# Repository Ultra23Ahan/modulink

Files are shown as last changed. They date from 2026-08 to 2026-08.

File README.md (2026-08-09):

## This specific repository is for the motor part of modulink.

What modulink is:

# ModuLink

ModuLink is a 90% 3d printed and modular system. It is a system of motors, gears, gearboxes, and many other components that can be used to create anything your heart desires.

# Usage Instructions

Make anything you want!

## Features

- Modular design
- Easy to assemble(Mostly)
- Easy to disassemble
- Easy to modify
- Easy to print
- Easy to use

## Components

### Motors

Motors are the main components of the ModuLink system. They are used to move the gears and gearboxes. The motors use a planetary gearbox, which leverage a few weak DC motors to create a stronger and more torque-ful motor.

### Gears

Gears are just standard gears. They are used to create the gearboxes. The motors rotate the gears.

### Gearboxes

Gearboxes are made up of gears, and the outer frame which holds the gears. The gearbox can be used to trade torque for speed, or vice versa. You can only have both if you have some small DC motors that produce more torque than the original intended ones.

## Why I made this

I wanted to make use of the random DC motors I owned so that I could create gear systems for my future projects and other random stuff, and I thought it would be fun to make a modular system that I could use to build anything I wanted.
I learnt about a planetary gearbox(from the [Torospin - Ruco by Kocyns](https://makerworld.com/en/models/2257094-torospin-ruco)) which can increase or decrease torque depending on where you rotate it from, and thus created this.

Images of the CAD designs:
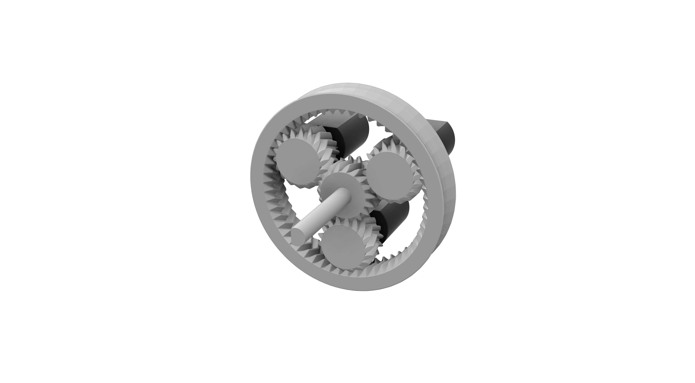
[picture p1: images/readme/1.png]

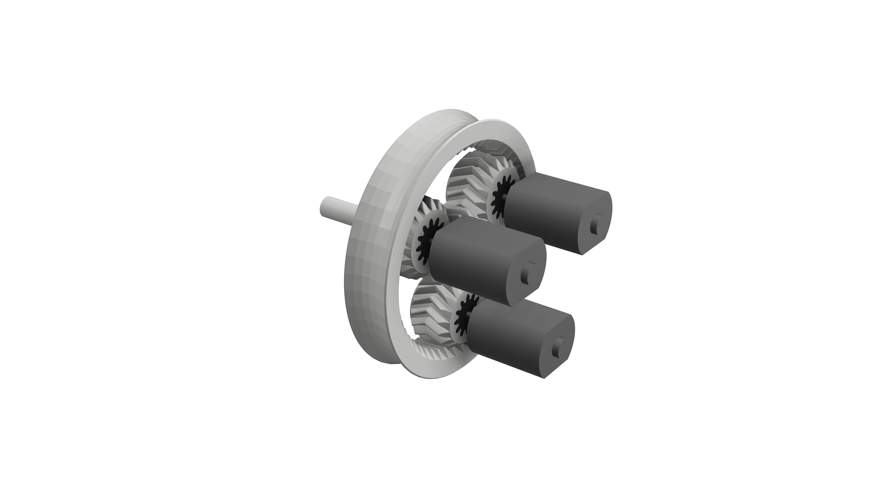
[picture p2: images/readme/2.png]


BOM(Bill of Materials) for this project:

| Item Name | Purpose | Misc. Notes | Price (1u INR) | Price (1u USD) | Quantity | Link | Shipping (INR) | Final Price (INR) | Final Price (USD) | Total Price (INR) | Total Price (USD) |
| --- | --- | --- | ---: | ---: | ---: | --- | ---: | ---: | ---: | ---: | ---: |
| SONY VTC6 18650 3000mAh Li-ion Battery | Batteries | This might seem like overkill but if I have a good battery I can optimize it for worse batteries. It also has better capacity. | 699 | 7.396042739 | 2 | https://robu.in/product/sony-vtc6-18650-li-ion-3000-mah-battery/ | 0 | 1398 | 14.79208548 | 1760 | 18.62235483 |
| 2S 20A Balance Version Li-Ion BMS 18650 Lithium-Ion Battery Protection Board | BMS | N/A | 99 | 1.047508199 | 1 | https://makerbazar.in/products/18650-bms-lithium-battery-protection-board?variant=48251033059568 | 60 | 159 | 1.682361653 | | |
| 18650 × 2 Battery Holder with Cover and On/Off Switch with DC Jack | Battery holder | N/A | 77 | 0.8147285993 | 1 | https://robu.in/product/18650-x-2-battery-holder-with-cover-and-on-off-switch-with-dc-jack/ | 0 | 77 | 0.8147285993 | | |
| 2S 8.4V 2A 18650 Lithium Battery Charger Module Type-C | For charging the batteries | N/A | 126 | 1.333192253 | 1 | https://robu.in/product/2s-8-4v-2a-18650-lithium-battery-charger-module-type-c/ | 0 | 126 | 1.333192253 | | |

This is the BOM for me, but it may be different for you as I already own the motors, and you may own some of these such as the batteries, thus this is not a comprehensive BOM that works for everyone. This BOM is also available as [a file](./BOM.csv)

Notes:
No PCB file as there are no PCBs(custom) for this project.
No guide for attaching componenst as this is just the inside of the motor and those instudtions will be there in the repo for the motor shell.

## Wiring

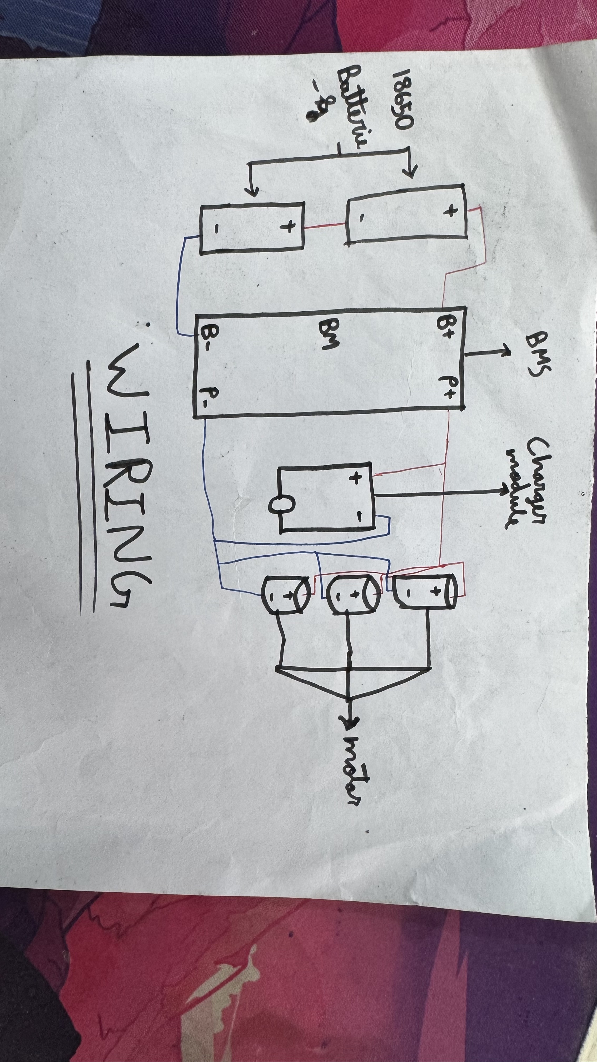
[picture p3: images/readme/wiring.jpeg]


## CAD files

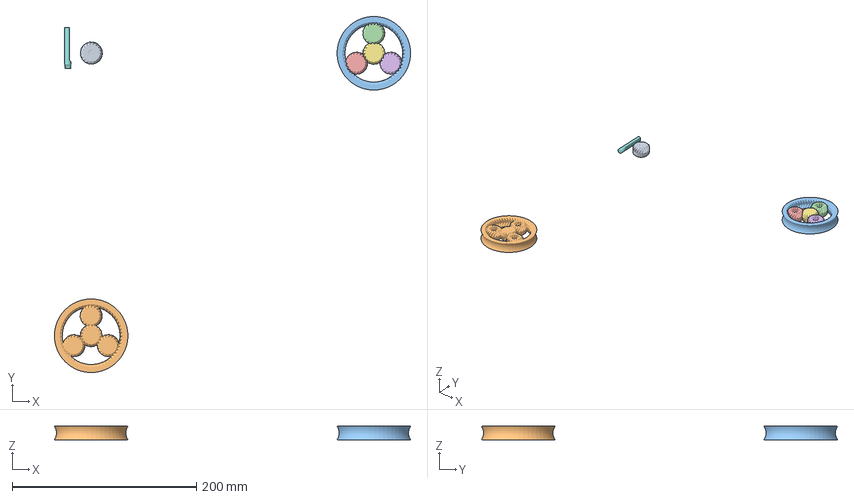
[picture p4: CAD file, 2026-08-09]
3mf/Modulink.3mf
386.9 x 386.7 x 15.0 mm
Sun Gear
Assembly
Assembly2_fixed.stl_1
Assembly2_fixed.stl_2
Assembly2_fixed.stl_3
Assembly2_fixed.stl_4
Assembly2_fixed.stl_5
Shaft

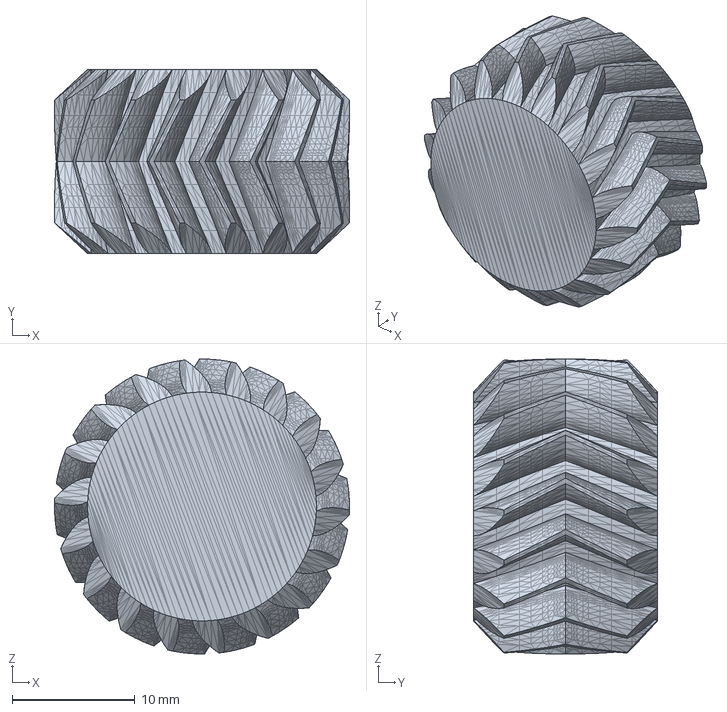
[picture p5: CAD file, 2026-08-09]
cad/Sun Gear.step
24.0 x 15.0 x 24.0 mm

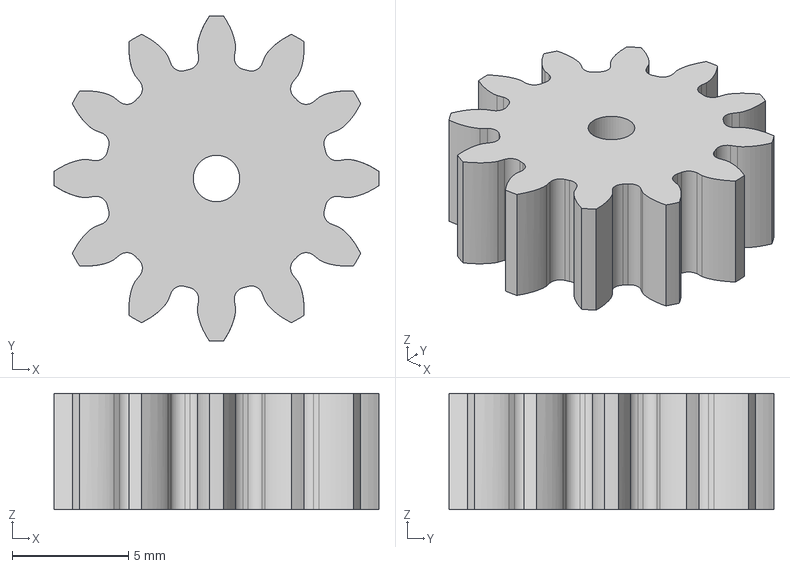
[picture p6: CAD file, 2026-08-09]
cad/SpurGearForModuLink.step
14.0 x 14.0 x 5.00 mm

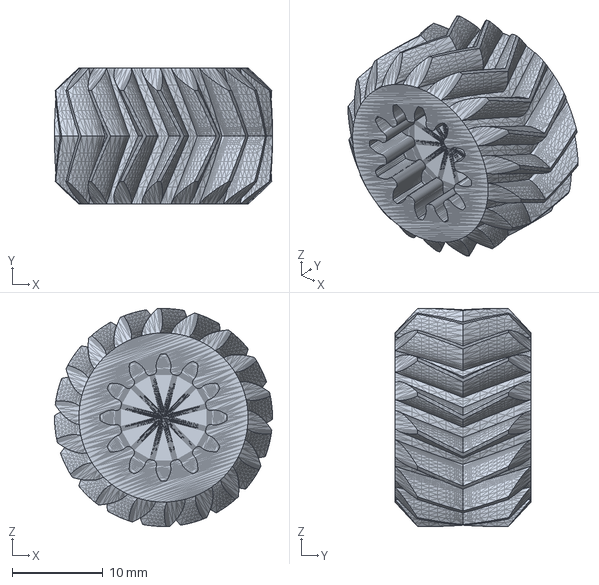
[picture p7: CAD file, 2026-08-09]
cad/planet gear.step
24.0 x 15.0 x 24.0 mm

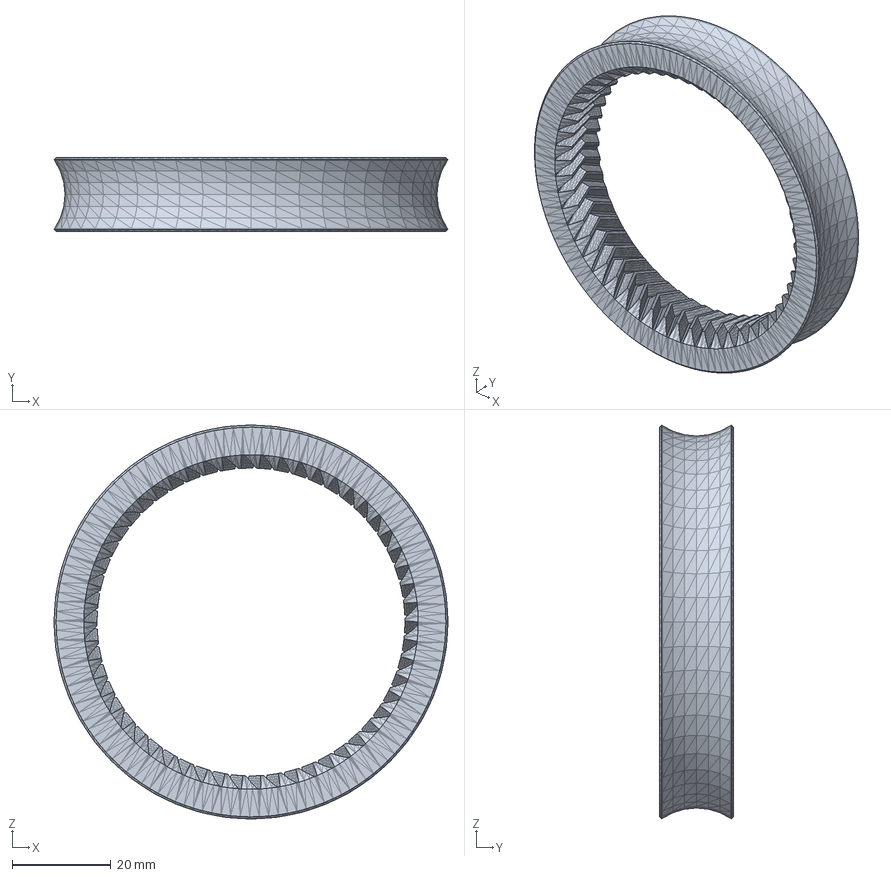
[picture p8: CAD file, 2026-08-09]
cad/Outer Ring.step
79.9 x 15.0 x 79.9 mm

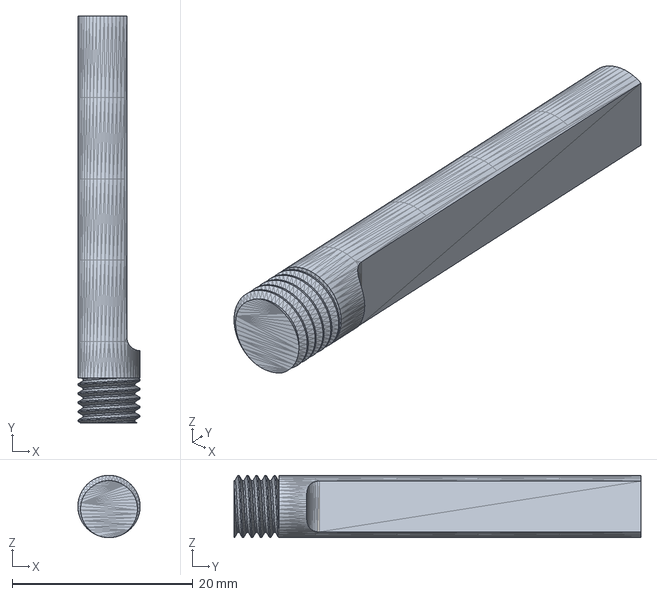
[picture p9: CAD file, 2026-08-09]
cad/Shaft.step
6.88 x 45.0 x 6.88 mm

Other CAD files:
3mf/SpurGearForModuLink.3mf

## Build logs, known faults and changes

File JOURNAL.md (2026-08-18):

---
title: 'ModuLink'
author: 'Ahan Das'
description: 'A 90% 3d printed modular system of custom motors, gears, and more.'
created_at: '2026-05-20'
---

# May 20: Did research and did a small test print

So I researched a about planetary gearboxes. I first thought of one like one I found online in the Torospin - Ruco which has a single shaft output by haviing spokes which follow the roation of the planet gears and make the pletary gear system more toroidal but I decided that the motor would make the output faster as if it is fast you can just use gear ratios and make it have more torque. I also learnt about involute gear teeth and how they work(as I thought it would be useful). I decided to use Herringbone gears as they are self aligning and tus the model can be made print-in-place and thus have no assembly required. I made a small test print of the core of the motor, and adjusted the settings to make it as lighter to reduce resistance. Still have to change settings and modify the design.

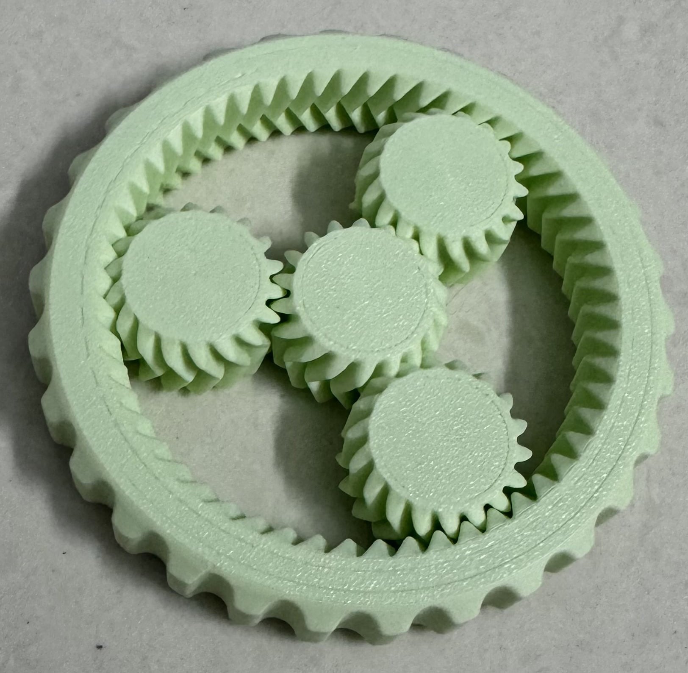
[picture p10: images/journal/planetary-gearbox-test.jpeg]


**Total time spent: 2 hours**

# May 21: Printed gears, planned, and designed motor core

I printed these gears, for the second last one I heated up the motor and pressed it into the hole, it worked pretty good, but I need to find a better and easier way to hold it in place.

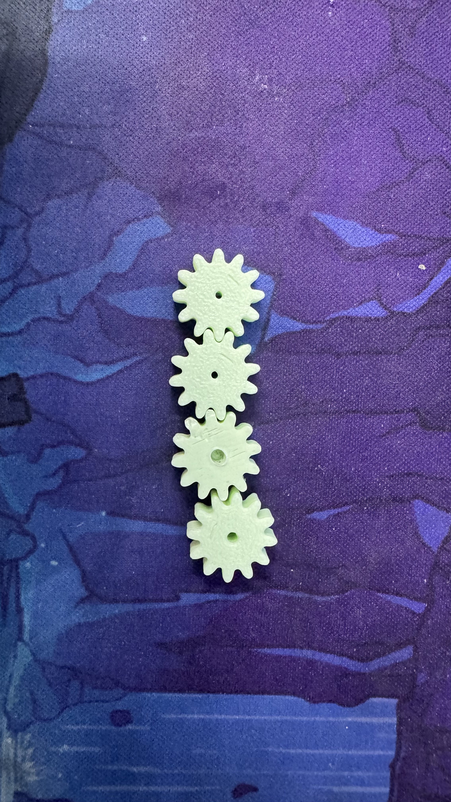
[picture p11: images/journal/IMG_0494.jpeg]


I tried to do a test and heat inserted the motor into one of the planetary gears, it worked but I decided that gears are far better.

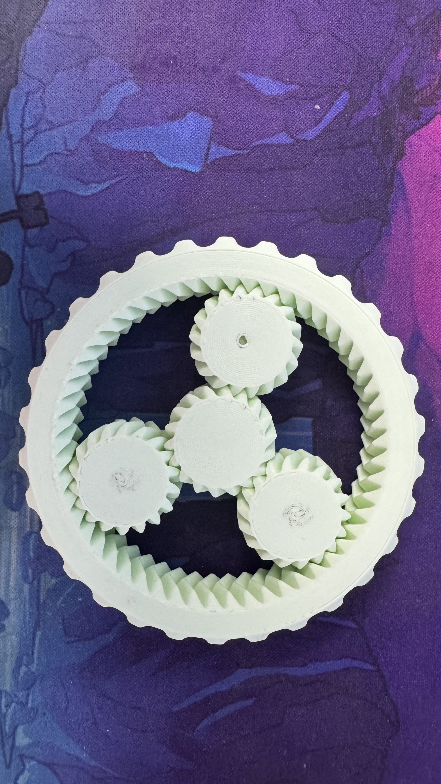
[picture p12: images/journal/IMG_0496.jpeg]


I modified the original planetary gear system to be lighter and I added indents for the gears that attach to the motors. The torerances are a bit too tight, so I adjusted the XY hole compensation to -0.035mm and that version is printing right now.

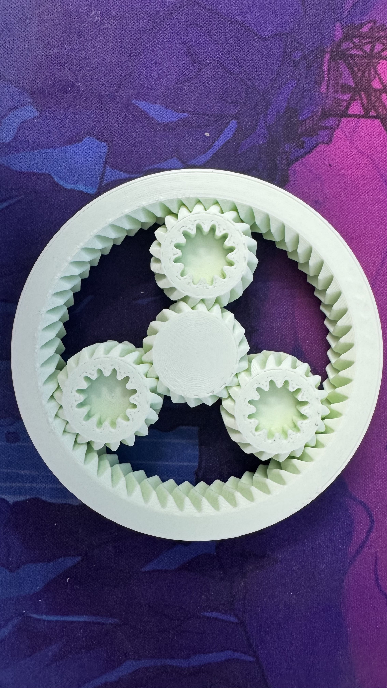
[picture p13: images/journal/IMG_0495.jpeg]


I modeled the motor core in Fusion 360 with motors and gears to see how it will all look when the motor core is assembled. I used negative parts from Bambu Studio to modify it, but this(↓) kept happening but I finally fixed it.

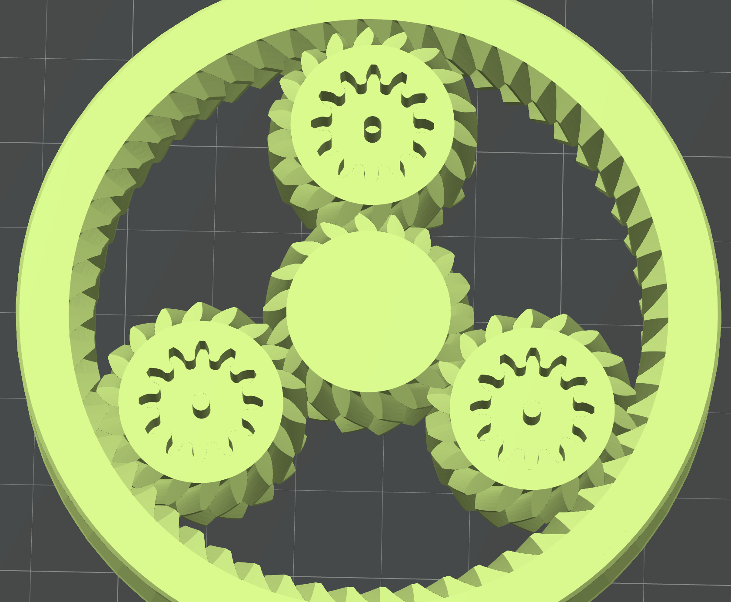
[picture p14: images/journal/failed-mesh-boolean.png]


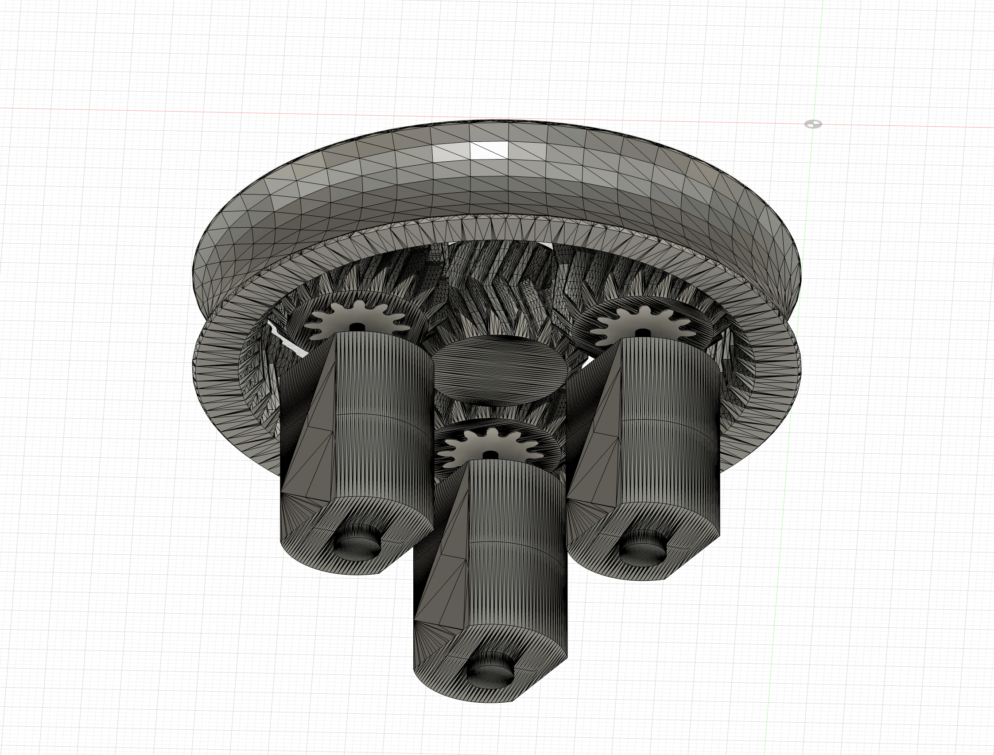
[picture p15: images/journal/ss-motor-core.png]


Okay, so this is a bit later but the fixed tolerances core is done and the gears almost fit but they don't quite fit. I need to increase XY hole compensation a bit more.

**Total time spent: 4.5 hours**

# May 23: Fixed tolerances, and planned more

I did a bunch of prints and in each print I changed this value called XY hole compensaton, but I thought that making it -ve would make the holes smaller, but it didn't. I realised that after like 3 prints, I could have saved so much filament. Also, I realised later on that I could also have just printed 1 gear instead of everything, and I would have saved a lot more filament. Well, you make mistakes, and you learn from them.

Photos:

Gear fits on motor perfectly

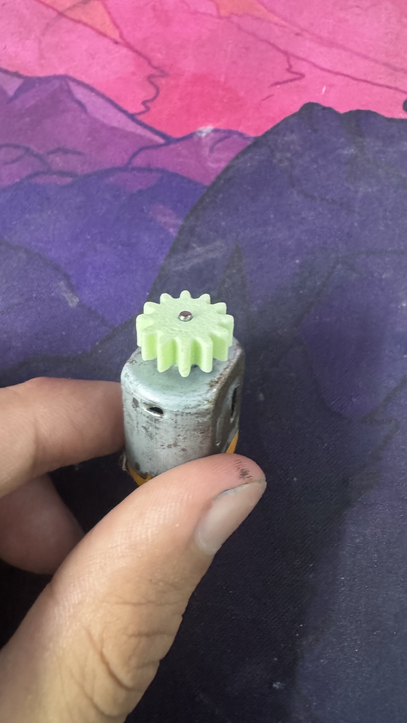
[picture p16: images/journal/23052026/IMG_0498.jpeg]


Final motor gear(3 as I am using 3 motors) and planetary gear, this is when I realised I could just print 1 gear and save filament and time

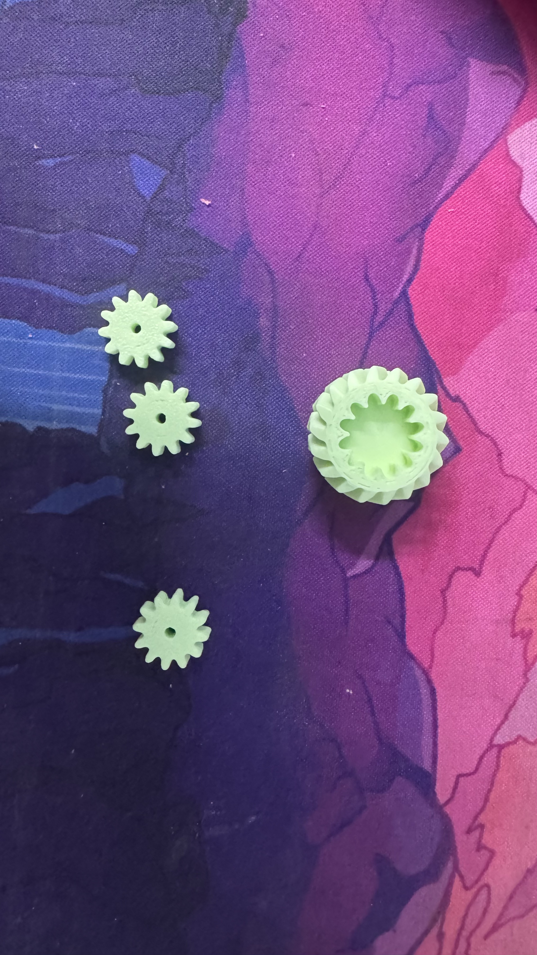
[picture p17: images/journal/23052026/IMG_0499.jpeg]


Total failed prints today:

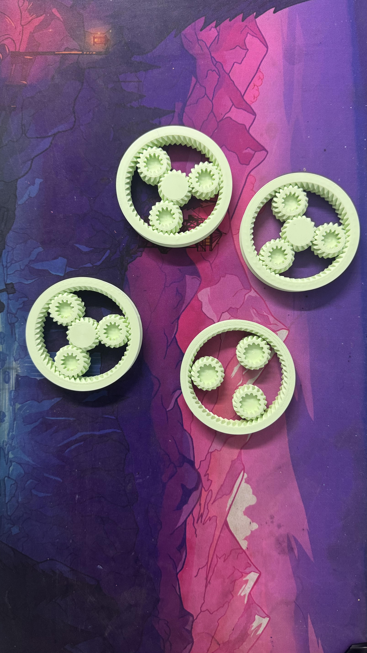
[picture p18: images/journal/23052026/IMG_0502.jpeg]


So, my plan for the future is that I will first create a "fast" motor as it is easier to make and I have already planned it out, and then later on I will either make a motor with torque or I will make an attachment for the fast motor that give it torque, but probably the latter.

Note: From now on I will be making folders for each day for the images to keep it more organised and so that I don't have to name them.

**Total time spent: 6 hours**

# May 24: Planned more and decided shaft shape

I didn't do much today(mostly because I have an exam tomorrow) except for choosing a shape to make the shaft, I didn't want to make a round shaft as it would slip, and in the end I chose to make a D shaped shaft(similar to the one below, image is from Google). Tomorrow, I will design the shaft in fusion and print the final motor core design , but I might make some more tweaks though.

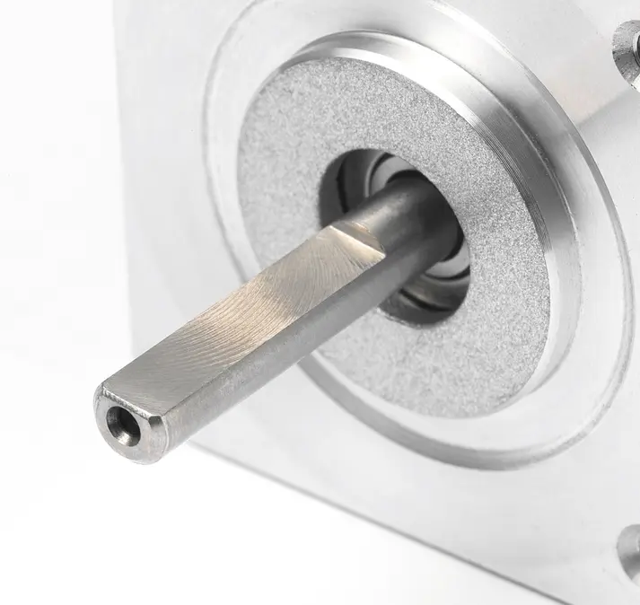
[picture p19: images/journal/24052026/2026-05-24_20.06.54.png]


**Total time spent: 1 hour**

# May 26: Designed the shaft and printed the motor core with correct gear tolerances

I designed the shaft in Fusion 360 and I printed the motor core with the correct tolerances for the gear indent. Since the shaft would easily break if it was directly attached to the sun gear by shear force, I designed the shaft to be attached to the sun gear by screw threads, but I think I shuld change the attachment method if this dosent work, as this is hard to do with tolerances.

Fusion 360 design:

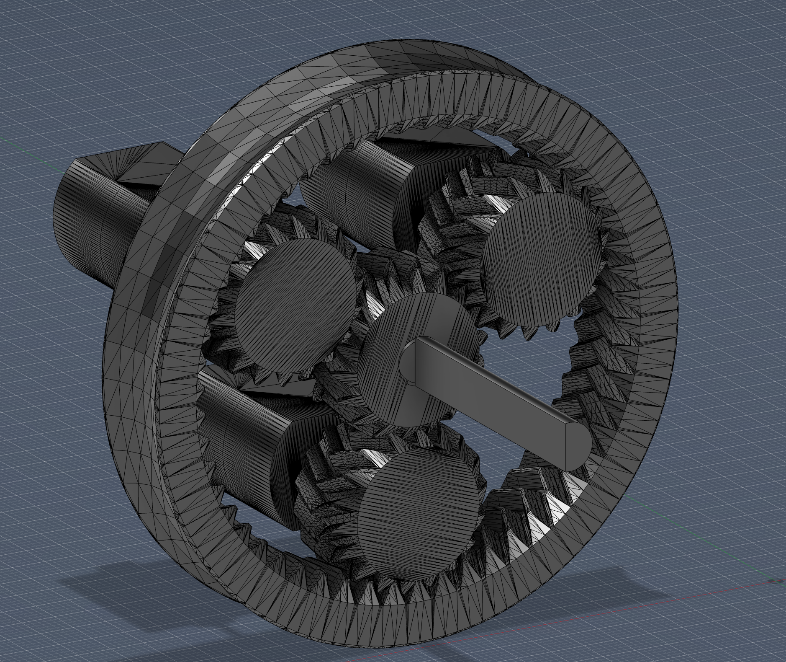
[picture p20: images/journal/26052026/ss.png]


Motor core print:

The XY hole compensation made the outer ring's hole bigger too, making the planetary gears loose but I found a way to fix it, I just need to colour paint the outer ring and then the XY hole compensation will not be applied to it. I'm going to print the shaft and new motor core tomorrow.

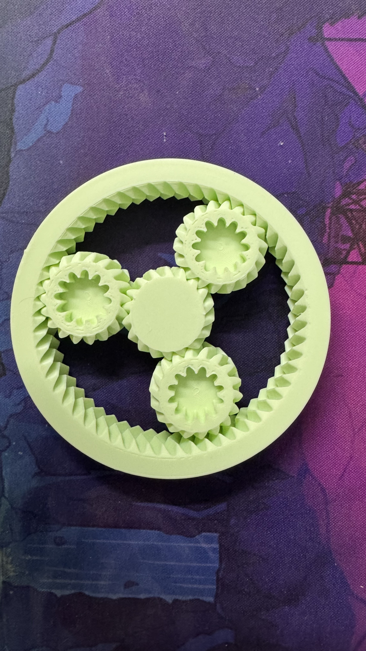
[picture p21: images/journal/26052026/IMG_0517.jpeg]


**Total time spent: 3.5 hours**

# May 29: Printed the shaft and central gear

Today is my birthday! :D I printed the shaft and the central gear, and tested some tolerances. The best result I got was with putting CA glue to fix it in place. The only problem I have left to resolve now is that the sun gear and planetary gears require different XY hole compensation values, and this model is hard to disassemble and reassemble, so I need to find out a fix for this.

I printed 3 test models for the tolerance testing(below), and I will print the final motor core tomorrow after finding a fix for this problem. Right now I'm thinking to either resolve it in cad or make people disassemble it and have different files, but that gets complicated.

The first model is just the screw and thread, but the last 2 are with CA glue. The last one with the black mark is the final model for the sun gear.

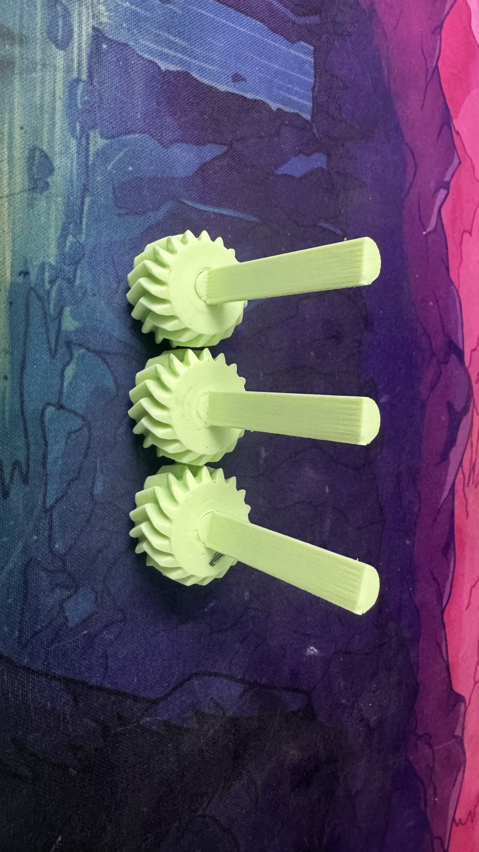
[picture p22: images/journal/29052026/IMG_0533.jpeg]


**Total time spent: 2 hours**

# June 2: Finished motor core

I did some tolerance testing and I finished the motor core.

The final model I ended up with was just the most simple solution I could think of.
What I did:
I knew the planetary gears and the the sun gear had different XY hole compensation values(0.35mm and 0.175mm respectively), and I knew that the shaft was a teeny bit loose and same for the gear holes. I didn't want to change it in fusion because the model fit perfecty so I just took the mean for the values which was 0.2625mm :P.

Finished motor core:

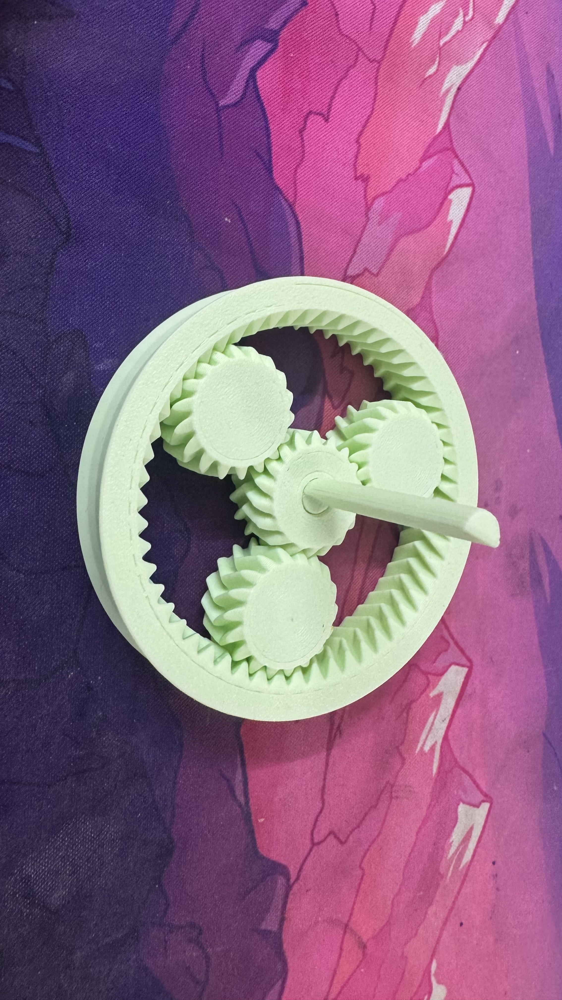
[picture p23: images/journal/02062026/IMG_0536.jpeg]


Gear fits perfectly!

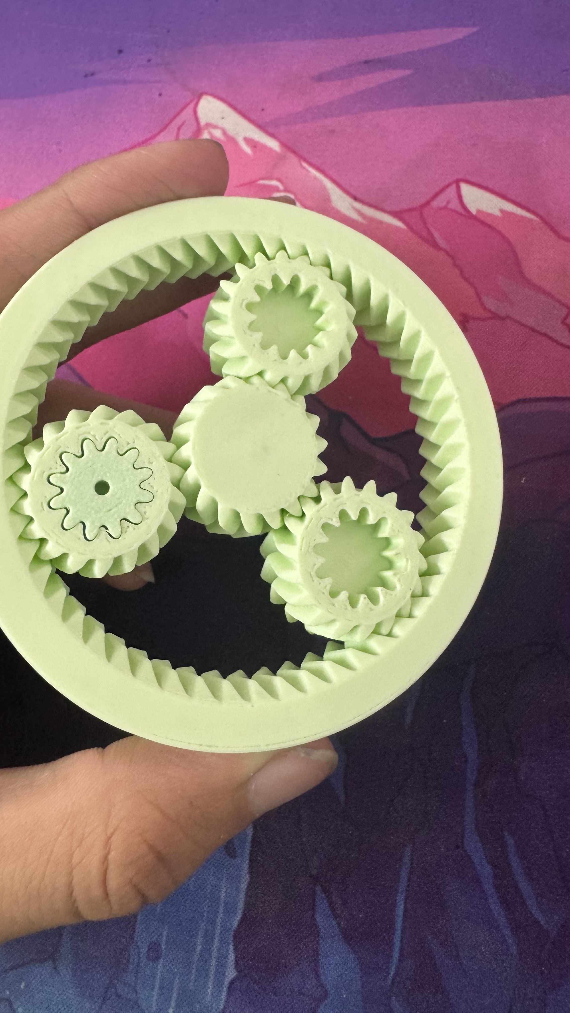
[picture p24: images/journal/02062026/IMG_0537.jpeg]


Also, now I have decided to make Modulink a full robotics system. I'm thinking to maybe make it a tier 3 project, but idk rn. After making the motor and gears, I will make an 18650 holder. I will also split this project into each of its modules because I need different parts for each module which all need to be shipped separately.

**Total time spent: 2.5 hours**

# June 3: Planned things

I was looking at the motor core and I realised that the shaft's flat part is much more than that of commercially sold motors, and also it isnt completely a D all the way through, it has a round part near where it connects to the sun gear, so I have decided to reduce the flat part of the shaft. Also, the shaft wobbles a bunch and this means that there is more room for error when you apply the CA glue, but I found that it levels flat by itself, so I don't think that should be much of a problem down the line, but I will scale the shaft up slightly to compensate for it.

Pictures of the shaft tilt:

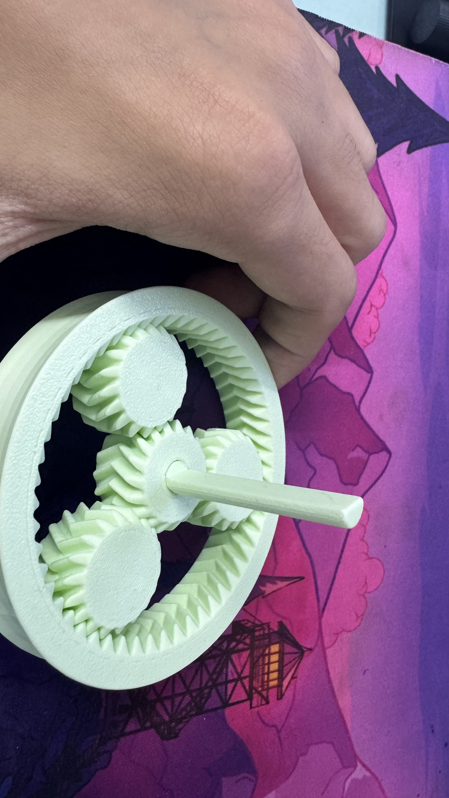
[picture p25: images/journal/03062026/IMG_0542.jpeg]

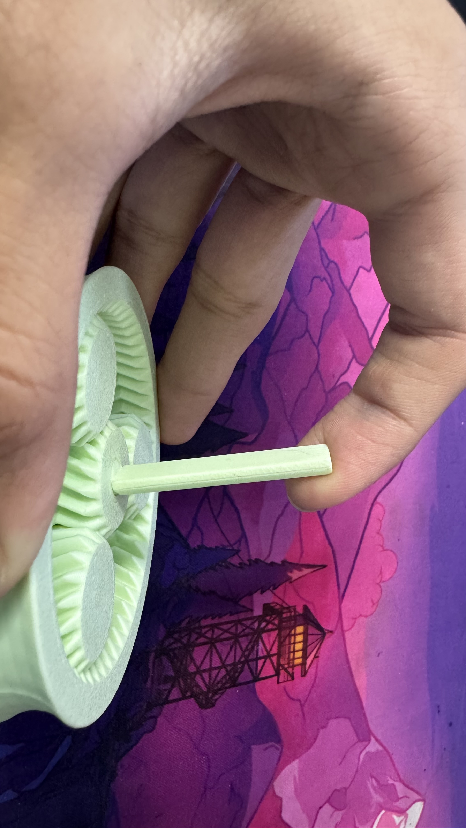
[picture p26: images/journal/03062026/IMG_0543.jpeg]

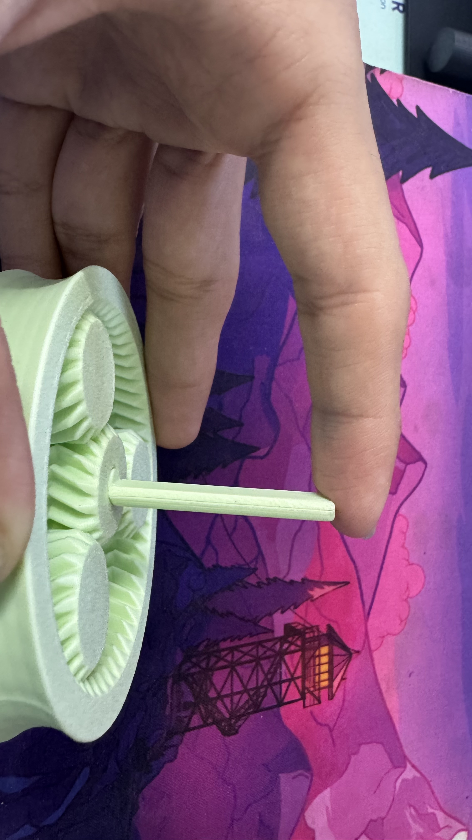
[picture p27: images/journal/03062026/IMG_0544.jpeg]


**Total time spent: 0.35 hours**

# June 4: Decisions, choices, and dilemmas

I was thinking about how I could connect the motor core to the shell of the motor, and I thought about connecting it with the motors, and by that I mean I will make a ring that fits aorund the 3 DC motors(place where ring has to go is in img below) and make that connect to the core instead of connecting the ring to the shell as the ring needs to spin for the motors to stay in place.

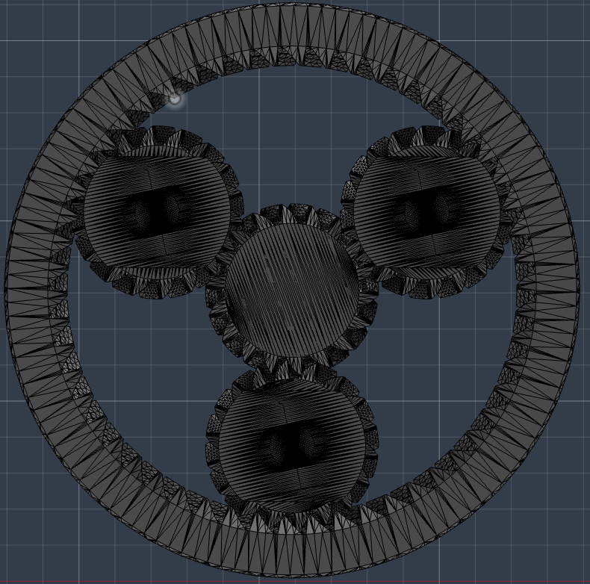
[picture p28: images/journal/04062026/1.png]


**Total time spent: 0.25 hours**

# June 10: Upgraded shaft

I discovered that the shaft had a weak point(I maaaayyy have dropped an IKEA Skadis on it but we don't talk about that) so I reduced the flat area of the shaft, reduced the amount that the D went, and filleted the part where it becomes a D in order to make it stronger.

Photos:
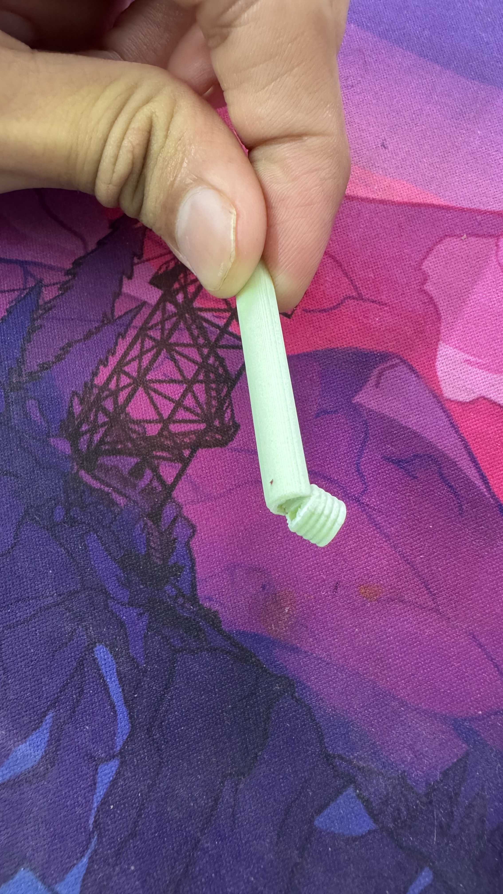
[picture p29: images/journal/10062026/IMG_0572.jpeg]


Design
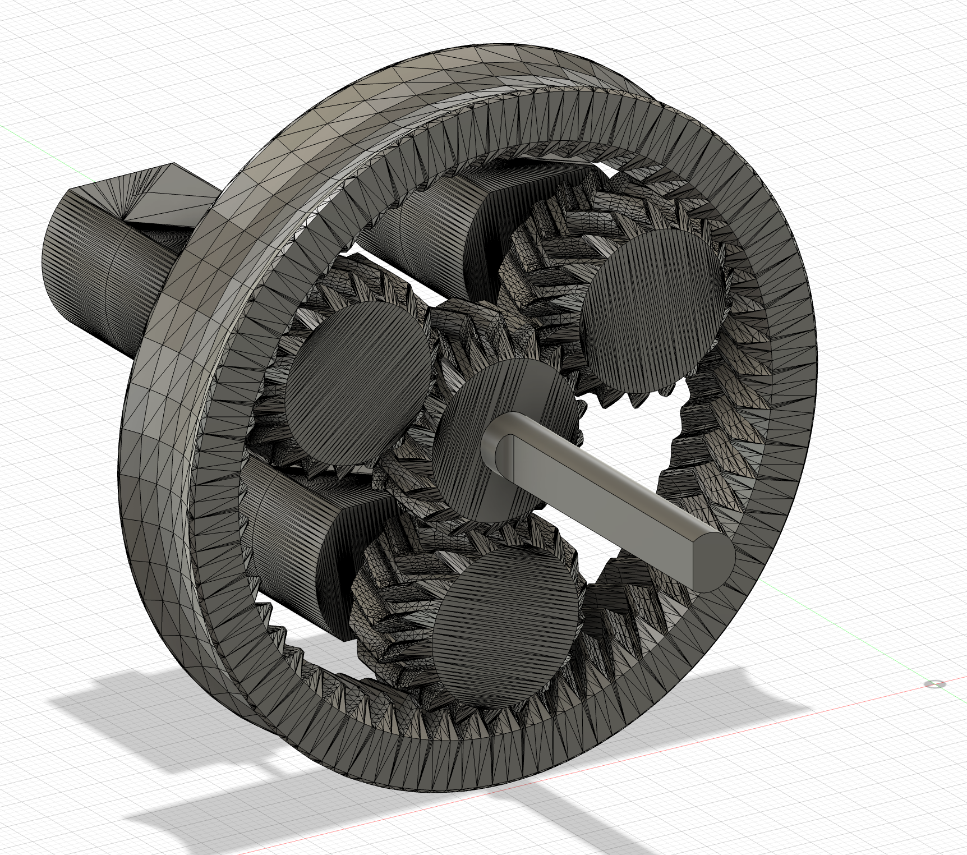
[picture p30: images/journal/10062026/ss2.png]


**Total time spent: 0.25 hours**

# June 13: Printed new shaft, motor core is FINALLY over

I printed the new shaft and it fits perfectly as expected, and looks much better and more realistic to actual DC D shafts.

Photos:
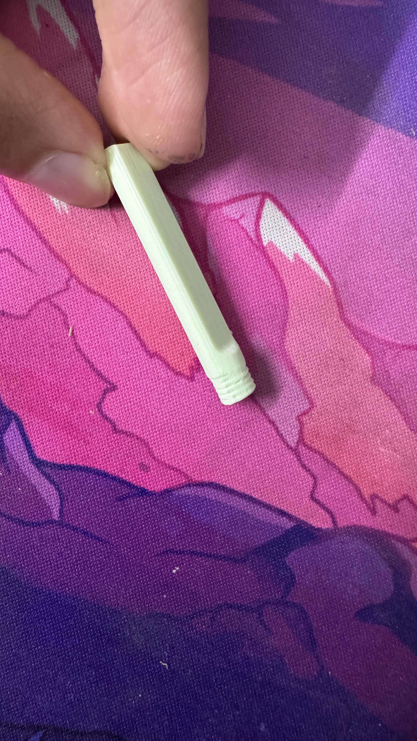
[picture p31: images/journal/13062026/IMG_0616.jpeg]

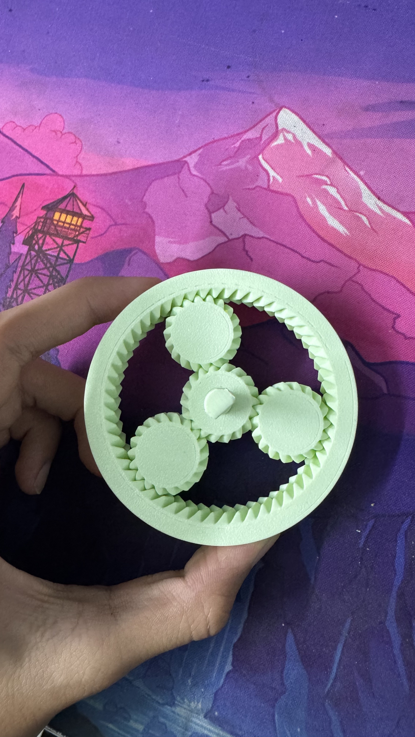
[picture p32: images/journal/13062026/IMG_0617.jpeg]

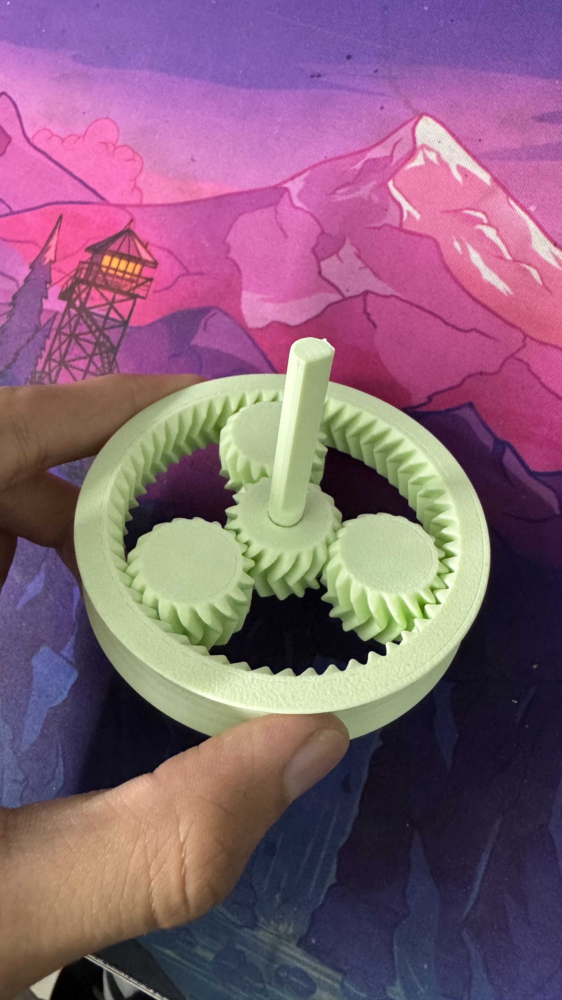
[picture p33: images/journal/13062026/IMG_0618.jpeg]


**Total time spent: 0.25 hours**

# June 23: Tested finished motor core, planned for the future of the motor

I tested the finished motor core with 1 DC motor, and I observed that it vibrated A LOT, but I think this is mainly due to there only being 1 motor and me holding it in my hand a a bit due to the tolerance of the outer ring. I think 3 would stabilize it when running at the same time, and also this vibration should be gone when the motor is actually connected to something(hopefully - this is an educated prediction, but a prediction nonetheless). I have also decided to make the motor shell a different project, and get the batteries and BMS etc for the motor core as this is the part which will actually do the spinning. It would also not make sense to require electronic components for just the shell, and the reason I am making it a different project is because I need the completed final WORKING motor core to design the shell(you might not understand why as of now, but you will understand after the shell in completed).

I did some research on what batteries to use and at first I thought of using alkaline batteries but I checked the types of batteries(yes, almost EVERY single type) and now had a dilemma between 21700s and 18650s. 21700s are more modern and have more capacity, but 18650s are more readily availabe and most people already own them. I wanted this project to be made as cheaply as possible and that meant going with the more readily available option and thus I decided to use 18650 batteries to run this(and a lot of research on the specific 18650 batteries I will be buying because I don't own them, and yes this contradicts my point of them being fairly common but we don't talk abt that). I am currently divided between using 2 batteries, 3 batteries in a 3S or 3P configuration, and 4 batteries in a 2P2S confoguration. Currently I am not sure, but I will do some research later on(aka tomorrow) and see what the best configuration is.

Motor vibration:
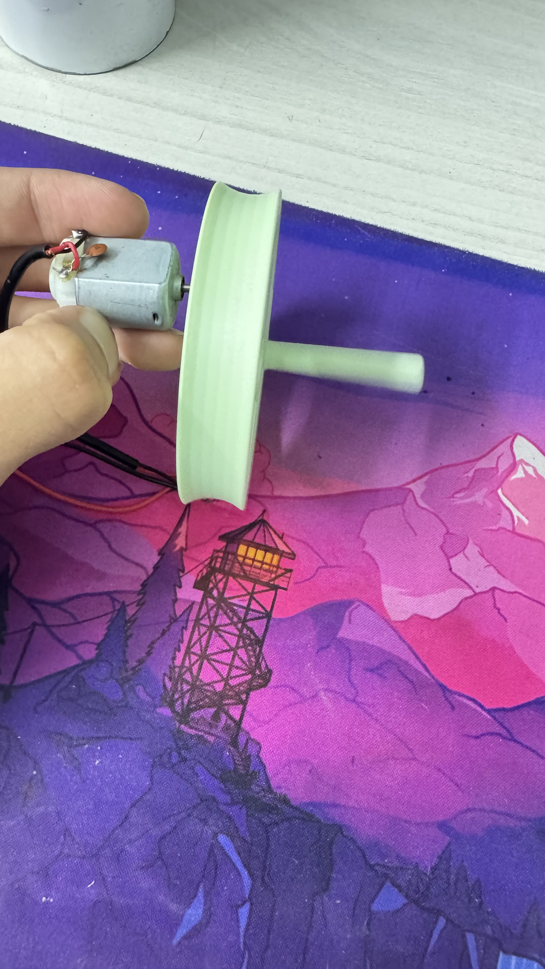
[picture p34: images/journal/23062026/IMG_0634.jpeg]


**Total time spent: 2.5 hours**

# June 24: Selected battery configuration, and did some wiring

I decided to use 2 18650 batteries in a 2S configuration, because I realized that a 2P2S was just too overkill for 3 tiny DC motors, and I don't need more than 45 of continuous runtime, and I don't think anyone else does either, but in care they do I will make battery packs later of various sizes after the first one(which is a 2S). For now, this is not a battery pack, it is only some loose batteries wired, I am going to make a battery holder later on as a seperate project.

I attempted to use KiCad but then realized that I don't know how to use it, tried to learn it for some time, then gave up, and I then proceeded to get stuck on the BMS part because KiCad does not have a BMS component and I did not have the knowledge and patience to figure it out, so I made a wiring diagram(using AI).

I got to here in KiCad:
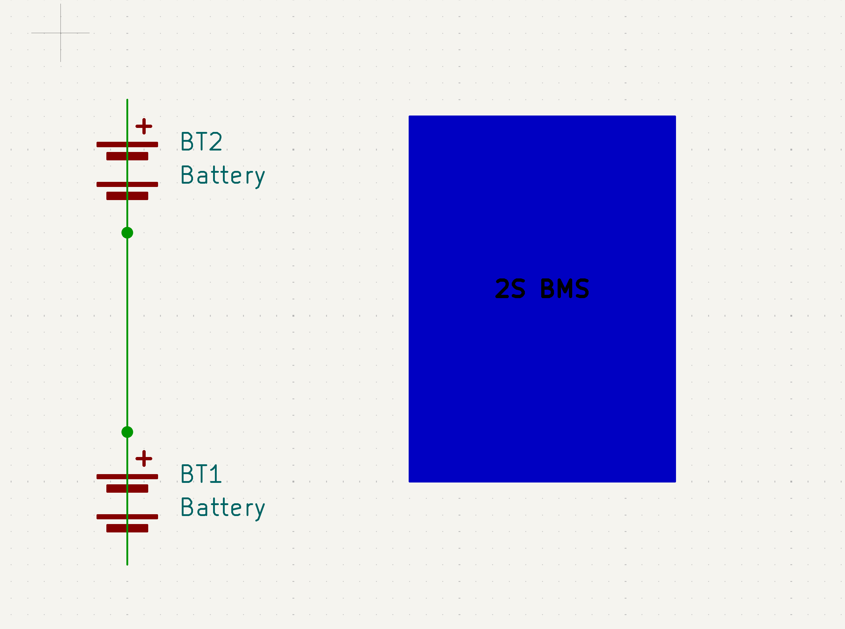
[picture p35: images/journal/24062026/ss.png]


AI wiring diagram:
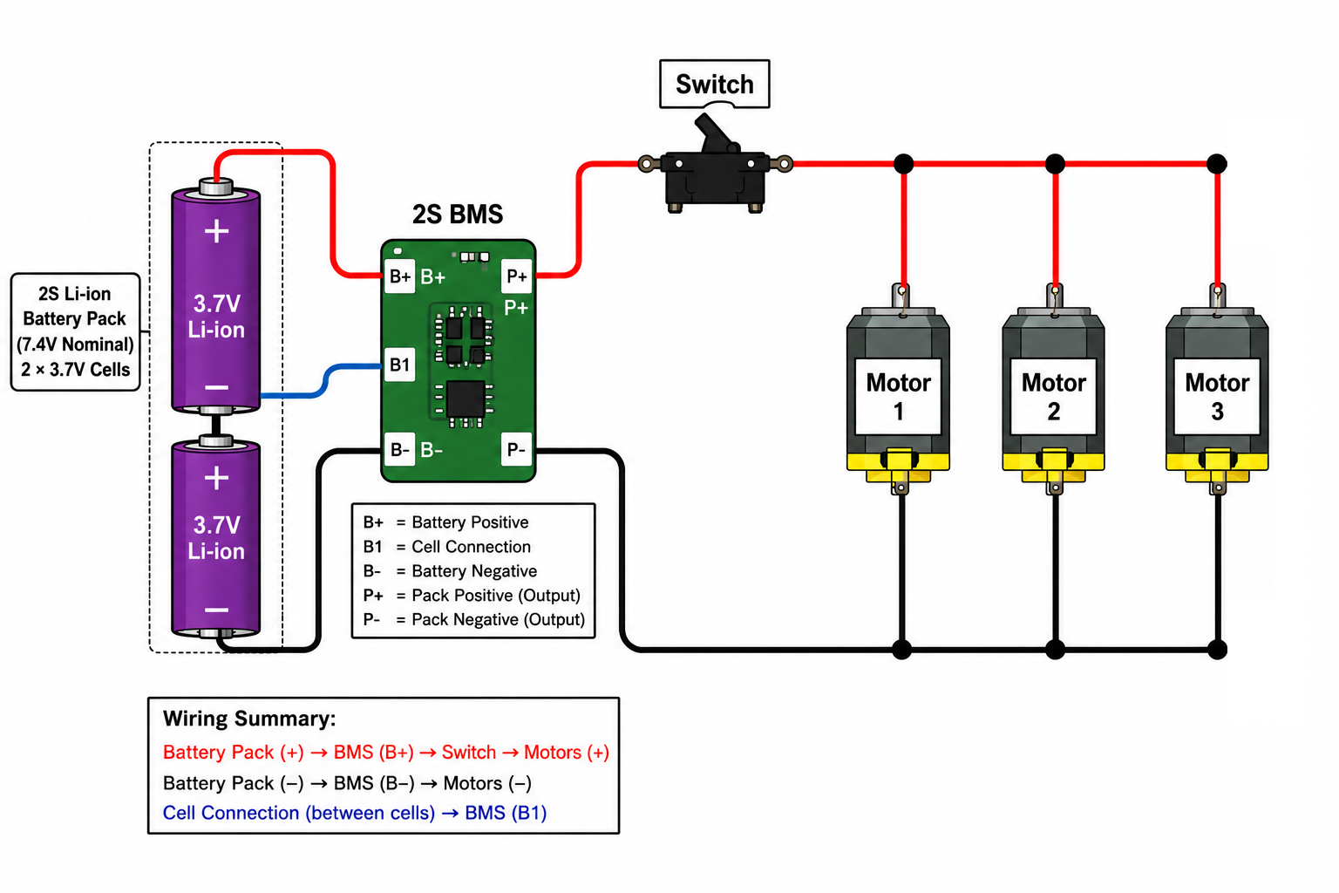
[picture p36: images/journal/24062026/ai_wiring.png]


The AI diagram is so much easier to understand than a KiCad one, the motor wiring is off, but I don't really think that affects how you understand how the wiring will be.

**Total time spent: 2.1 hours**

# June 26: Increased sun gear infill, etc stuff

I think this project is finally over, now I just have to make the BOM for the BMS and the batteries.

I found a fatal flaw in the sun gear, it was too hollow so i increased the infill to 45% gyroid to make it stronger. The other gears are fine with less infill.

So this happened
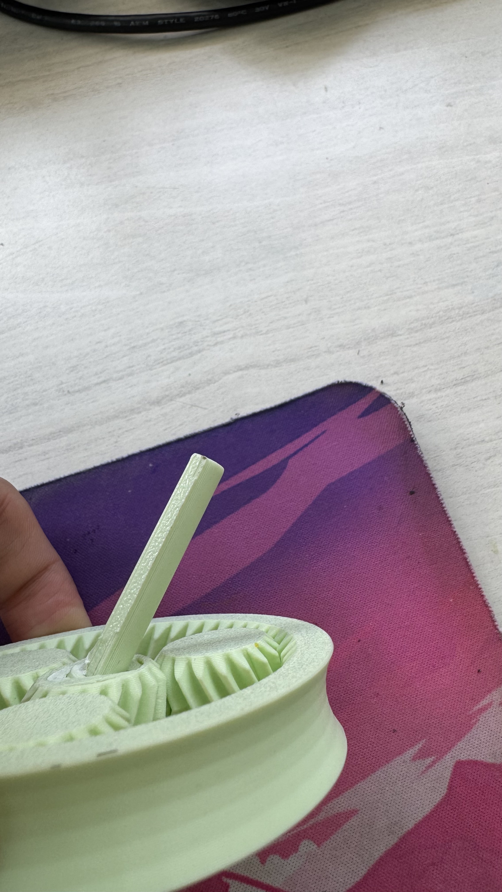
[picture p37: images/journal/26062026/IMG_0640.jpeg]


Hollowness of the sun gear
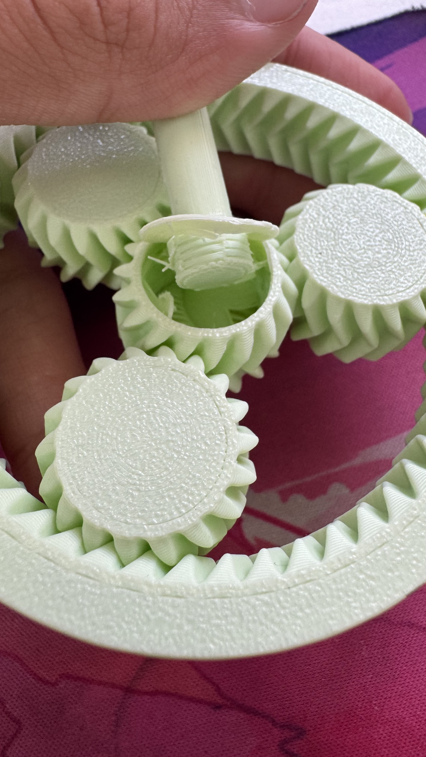
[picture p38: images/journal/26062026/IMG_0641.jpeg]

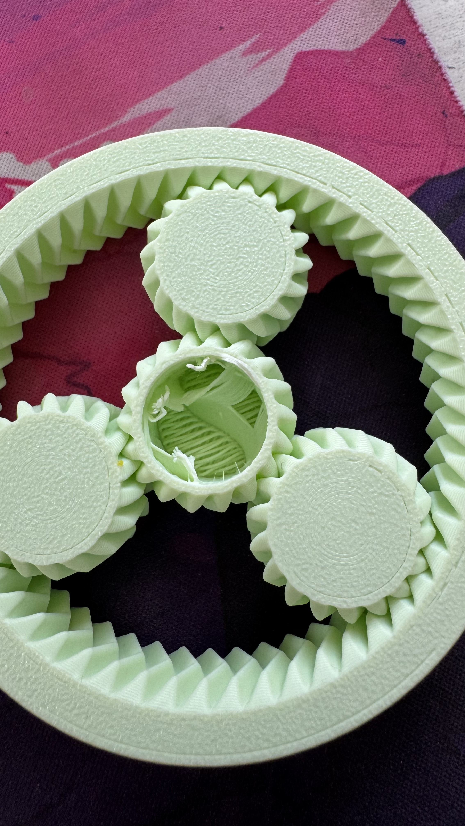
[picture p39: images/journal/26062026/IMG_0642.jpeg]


I also updated the 3MF. Currently it's only for Bambu Studio.

**Total time spent: 1.5 hours**

# June 29: Did a bunch of research, started making BOM

I did way too much research on the battery. At first I was thinking of using some random 18650s off of Robocraze which were surprisingly cheap. I looked into it more and found out that the batteries are not ideal for....anything basically except very lowend projects(in a 2S at least). I then looked on Robu and found a plethora(yes, plethora).I couldnt decide between the samsung 30Q and the sony murata vtc6, but I decided the latter as it is(according to the internet and reputable sources I could find) better.
I just CANNOT find a 2S BMS for the battery, but I found one on robu which is out of stock, so I will likely use that.

The BMS I want is the last one of this list:


Current BOM


**Total time spent: 4 hours**

# July 4: Finished BOM and thus the project

I did research to find the BMS. I looked everywhere that I knew and had this absolutely genius idea of looking at the forge docs as I had remembered that there was a section about reputable marketplaces that accepted HCB cards. I had already checked Robocraze and Robu, and EBhoot was taken down? I then went to MakerBazar and instantly found it :P. So now I finished the BOM, and I think the project is oficially done now!



The battery holder I selected is currently out of stock, but I presume it will be available soon.

I also decided that the motor shell would have a USB-C port(yes, I have added it to the BOM) so you can charge it directly and then you don't have to use a diferent charger. The only thing I'm unsure about is if the motors will also run while its charging, but that can also been good because if the motors move, they smoothen out the motor core and it runs better overall. Or you can just disassemble the motor core(aka remove the planetary gear system so only the gears turn).

**Total time spent: 1.25 hours**

# July 22: Made finished wiring diagram

So I may have asked AI to make the wiring diagram because idk how to use KiCad and its also too overkill for this simple project and diagram.



**Total time spent: 0.166 hours**

# July 30: Feedback!!!

So, my project got returned(again) and ace6rings gave me stuff to improve on and re-submit for review.

"Hey! Cool idea, but I have to return this because your project will most likely not work. Planetary gear systems can take multiple input motors at the same time but having multiple on the planet gears won't work. The motors would need to be perfectly synced for the system to not stall and the wires will go all over the place when it runs. Also, use step files instead of stl in your repo and ai generated wiring diagrams are not allowed."

The motor core will work, I tested it, and you are right about the wires going all over the place BUT only if the outer ring dosen't spin. In my motor core, the outer ring DOES spin, letting the motors stay in one place, and let the shaft still run, with the caveat of the outer ring spinning so I have to find a different way to hold the motor core in place inside the shell.

The motors don't need to be perfectly synced, if one motor is slightly too fast more load will be on that motor and the rest of the motors will work fine, making the shaft stable. I also have a balance BMS, which _should_ make them more stable and in sync.

For today I'll only change the stl files into STEP.


**Total time spent: 0.25 hours**

# August 9: Re-did wiring

So I may have procrastinated a bit.....
I also couldn't find any software which was easy to use and didnt have a learning curve so I had this absolutely transcendent idea to just make it on paper :P

So here is the wiring:



**Total time spent: 0.166 hours**

# August 18: Made journals more detailed

More Feedback!!!:

"hey, can you add some detail to your journals, especially the research ones?" from vulcan

So I made the journals more detailed, thats about it.
Maybe a bit **too** detailed...

**Total time spent: 0.25 hours**
